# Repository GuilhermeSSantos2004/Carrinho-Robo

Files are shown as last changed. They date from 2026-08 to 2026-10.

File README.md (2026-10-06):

# Carrinho-robô com ESP32 — CUBI-04

> **Project-based Maker Lab — FIAP**  
> **Grupo: Start-up One**

## Integrantes

| Nome | RM |
|---|---|
| Enricco Rossi de Souza Carvalho Miranda | RM551717 |
| Gabriel Marquez Trevisan | RM99227 |
| Guilherme Silva dos Santos | RM551168 |
| Danilo Urze Aldred | RM99465 |
| Laura Claro Mathias | RM98747 |

---

## Resultado final

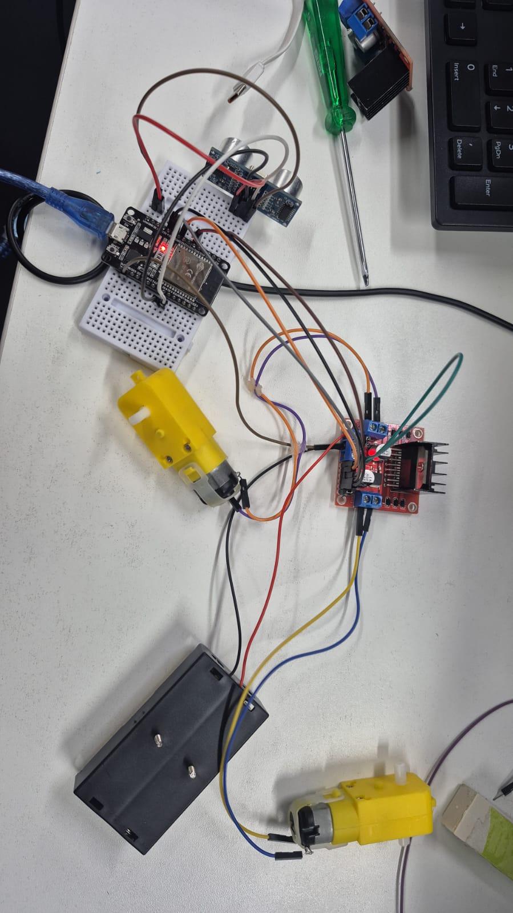
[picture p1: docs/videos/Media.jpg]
Carrinho-robô CUBI-04 montado


O **CUBI-04** é um carrinho-robô funcional desenvolvido para integrar **projeto mecânico, fabricação digital, eletrônica, programação, sensores e comunicação sem fio**. O protótipo utiliza chassi, carenagem e suportes desenvolvidos para impressão 3D, quatro motores TT, ESP32, ponte H L298N e sensores.

### Vídeo de demonstração

- [▶ Assistir ao vídeo final do carrinho](WhatsApp%20Video%202026-09-17%20at%207.53.06%20PM.mp4)
- [▶ Vídeo de evidência em `docs/videos`](docs/videos/MicrosoftTeams-video.mp4)

---

## Funcionalidades implementadas

- 4 motores TT, dois por lado;
- movimentação para frente e para trás;
- curvas para esquerda e direita;
- parada;
- controle remoto pelo celular via Wi-Fi;
- ESP32 operando como Access Point e servidor web;
- controle de velocidade dos motores;
- sensor ultrassônico HC-SR04 para estacionamento de ré;
- bipes progressivos conforme o obstáculo se aproxima;
- bloqueio/interrupção da ré a aproximadamente 5 cm;
- LDR para leitura de luminosidade;
- interface web com modos AUTO, CLARO e ESCURO;
- chassi, carenagem, suportes e travas fabricados em impressão 3D.

---

## Arquitetura do projeto

O celular conecta diretamente à rede criada pelo ESP32. Pela interface web, o usuário envia comandos de movimento. O ESP32 controla a ponte H L298N, que aciona os quatro motores. O HC-SR04 mede a distância durante a ré e o LDR fornece a leitura de luminosidade.

Diagrama elétrico

Documentação elétrica completa: [`hardware/arquitetura/README.md`](hardware/arquitetura/README.md).

---

## Projeto mecânico e fabricação 3D

O desenvolvimento mecânico foi **iterativo**. As peças foram modeladas, impressas, testadas fisicamente e corrigidas de acordo com os problemas encontrados na montagem.

### T01 — chassi/base final

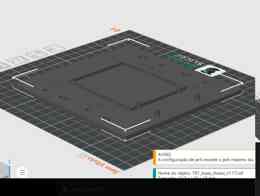
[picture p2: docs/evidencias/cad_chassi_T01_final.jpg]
T01 chassi final


Base estrutural otimizada para aproximadamente **147 × 140 × 10 mm**, com pontos de fixação e espaço para os componentes.

### T02 — carenagem final

T02 carenagem final

A carenagem foi redesenhada para reduzir material e manter acesso aos componentes. As aberturas laterais são funcionais e permitem a passagem/encaixe dos conjuntos dos motores.

### Suportes dos motores

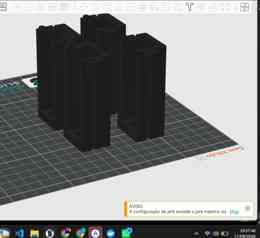
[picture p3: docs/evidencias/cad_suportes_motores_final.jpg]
Suportes finais


Os suportes passaram por várias versões até o conjunto final T03A/T03B v7.

| Peça | Função |
|---|---|
| T01 | Base/chassi estrutural |
| T02 | Carenagem com aberturas funcionais |
| T03A | Suporte do motor v7 |
| T03B | Presilha de retenção v7 |
| T04 | Tampa opcional de 2 mm |
| T05 | Trava vertical suporte ↔ chassi |
| T06 | Pino/parafuso impresso; dois por motor |

Arquivos STL/STEP, fontes e versões: [`cad/`](cad/).  
Pacote final: [`cad/PACOTE_FINAL_VERIFICADO.md`](cad/PACOTE_FINAL_VERIFICADO.md).

---

## Evolução e problemas encontrados

O repositório preserva versões anteriores para demonstrar o **processo de engenharia**, não apenas o resultado final.

Durante os testes foram encontrados problemas reais de fabricação e montagem, entre eles:

- folga lateral nos primeiros suportes de motor;
- laterais frágeis em versões anteriores;
- desalinhamento entre motor, eixo, roda e chassi;
- necessidade de adequação à largura real de aproximadamente 22 mm do motor TT;
- necessidade de reforçar frente e laterais dos suportes;
- ajustes nos furos, parafusos, porcas e travas inferiores;
- colisões e cortes CAD fora do material útil;
- corpos desconectados em versões intermediárias;
- ajustes no encaixe do HC-SR04;
- excesso de suporte detectado durante o fatiamento;
- revisão das aberturas laterais da carenagem para permitir a montagem dos motores.

As correções incluíram centralização do eixo, redução das folgas, reforço estrutural, reposicionamento dos suportes e revisão da carenagem. O histórico detalhado está em [`historico/HISTORICO_PROJETO_CUBI04.md`](historico/HISTORICO_PROJETO_CUBI04.md).

### Registro visual do processo

| Etapa 1 | Etapa 2 |
|---|---|
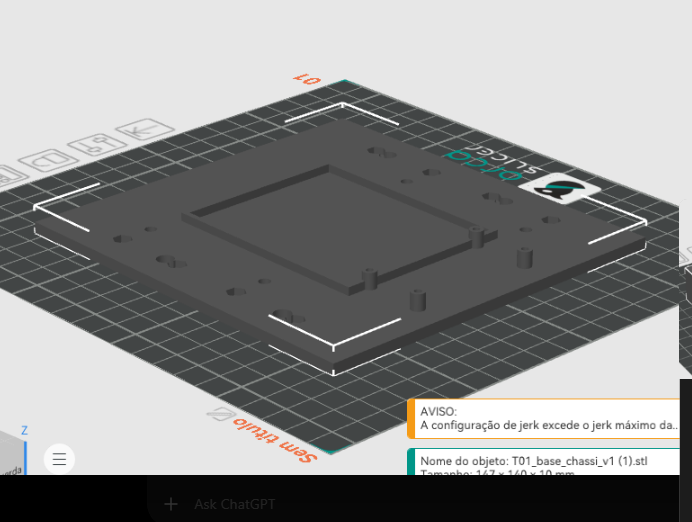
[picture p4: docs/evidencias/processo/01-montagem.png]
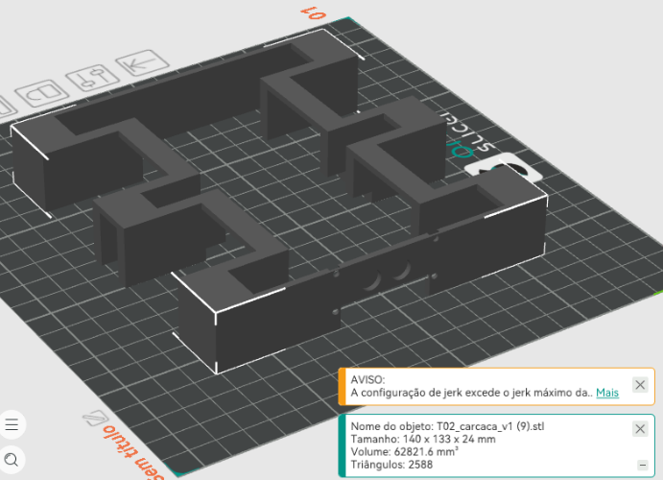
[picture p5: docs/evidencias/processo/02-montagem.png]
|  |  |
| **Etapa 3** | **Etapa 4** |
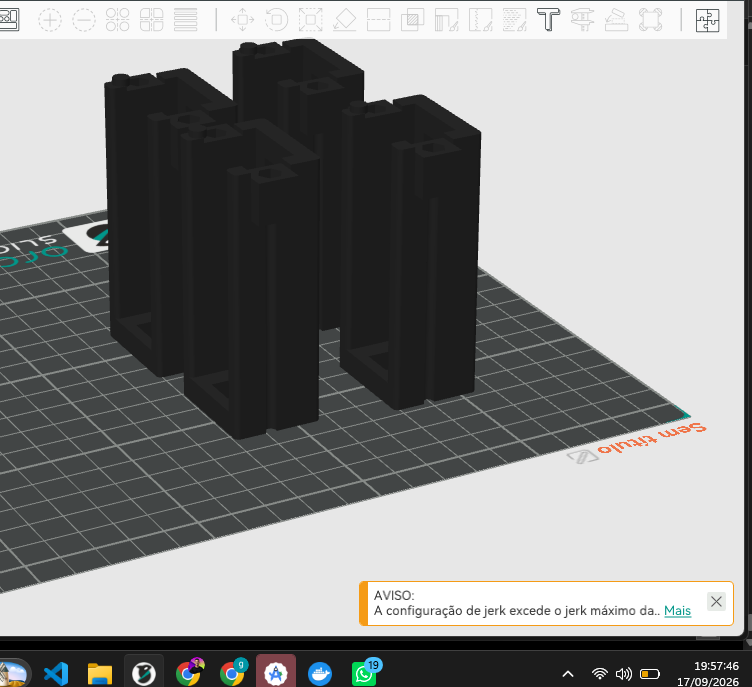
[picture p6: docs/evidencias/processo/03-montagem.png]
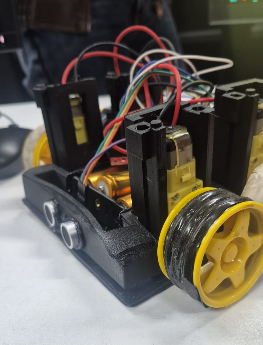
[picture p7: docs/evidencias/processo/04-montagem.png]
|  |  |

Essas imagens foram retiradas da raiz do repositório e centralizadas em `docs/evidencias/processo/`, mantendo a raiz limpa e as evidências fáceis de localizar.

---

## Hardware

| Componente | Especificação / uso |
|---|---|
| ESP32 | DevKit V1 / NodeMCU-ESP32 |
| Ponte H | L298N, dois canais |
| Motores | 4 × TT amarelos, 3–6 V, redução 48:1 |
| Alimentação | suporte com 3 × 18650 em série |
| Ultrassônico | HC-SR04 |
| Luminosidade | LDR |
| Estrutura | peças próprias impressas em 3D |

Lista detalhada: [`hardware/componentes/README.md`](hardware/componentes/README.md).

### ESP32 ↔ L298N

| L298N | ESP32 | Função |
|---|---:|---|
| ENA | GPIO 25 | controle canal A |
| IN1 | GPIO 26 | direção A |
| IN2 | GPIO 27 | direção A |
| ENB | GPIO 33 | controle canal B |
| IN3 | GPIO 32 | direção B |
| IN4 | GPIO 23 | direção B |
| GND | GND | referência comum |

### HC-SR04

| HC-SR04 | ESP32 |
|---|---:|
| VCC | 5 V |
| GND | GND comum |
| TRIG | GPIO 18 |
| ECHO | GPIO 19 via divisor resistivo |

> **Atenção:** o ECHO do HC-SR04 trabalha em nível de 5 V e deve chegar ao ESP32 através do divisor resistivo previsto no projeto.

### Alimentação

O suporte utiliza três células 18650 em série, resultando em aproximadamente **11,1 V nominais e até 12,6 V com as células totalmente carregadas**. O pack alimenta a entrada de potência da L298N. Durante testes, o ESP32 pode ser alimentado separadamente por USB/power bank, sempre mantendo **GND comum**.

Os motores TT são especificados para 3–6 V; portanto, a diferença entre a tensão do pack e a tensão adequada aos motores é uma limitação conhecida do protótipo e deve ser considerada na alimentação/controle.

---

## Software e controle remoto

Firmware principal: [`src/codigo.ino`](src/codigo.ino).  
Versão funcional preservada: [`src/v0.3/carrinho_robo_v0_3.ino`](src/v0.3/carrinho_robo_v0_3.ino).  
Documentação: [`src/README.md`](src/README.md).

O firmware integra Wi-Fi Access Point, servidor HTTP, comandos direcionais, acionamento dos motores, HC-SR04, bloqueio de ré, alertas sonoros no navegador, LDR, interface responsiva para celular e logs de diagnóstico.

### Como executar

1. Confira toda a fiação com o circuito desligado.
2. Alimente o ESP32 por USB/power bank durante os primeiros testes.
3. Abra [`src/codigo.ino`](src/codigo.ino) na Arduino IDE.
4. Selecione a placa compatível com o ESP32 utilizado.
5. Faça o upload do firmware.
6. Abra o Serial Monitor em `115200 baud`.
7. Conecte o celular à rede Wi-Fi criada pelo ESP32.
8. Abra no navegador o endereço exibido/configurado pelo firmware.
9. Teste primeiro parada e movimentos em condição segura, com as rodas livres.
10. Teste o HC-SR04 durante a ré aproximando um obstáculo gradualmente.
11. Varie a iluminação sobre o LDR e confira a leitura/interface.

---

## Experimentos em fase de teste

- [Aula 19 — práticas iniciais com TinyML](experimentos/tinyml-aula19/README.md): leitura bruta do HC-SR04, pré-processamento, classes perto/longe e roteiro para coletar o CSV. **Medições físicas e dataset real pendentes.** Códigos isolados do firmware principal.
- [Tarefa 21 — Inferência TinyML no ESP32](docs/TAREFA21_TINYML.md): inferência com os três HC-SR04 frontais, quatro classes (livre/esquerda/centro/direita), `src/tinyml_inferencia.ino`, `model/model.h` e `docs/dataset.csv`. O dataset desta etapa é **sintético e identificado como tal**; a validação física deve ser demonstrada no vídeo da atividade.

---

## Planejamento e documentação

A organização do projeto também registra requisitos, prioridades e evolução:

- [`organizacao/BACKLOG.md`](organizacao/BACKLOG.md) — backlog;
- [`organizacao/MVP.md`](organizacao/MVP.md) — definição do MVP;
- [`organizacao/MOSCOW.md`](organizacao/MOSCOW.md) — priorização MoSCoW;
- [`organizacao/KANBAN.md`](organizacao/KANBAN.md) — acompanhamento das atividades;
- [`organizacao/DEPENDENCIAS.md`](organizacao/DEPENDENCIAS.md) — dependências;
- [`CHECKPOINT_01_VALIDACAO.md`](CHECKPOINT_01_VALIDACAO.md) — validação da entrega;
- [`docs/EVIDENCIAS_CHECKPOINT.md`](docs/EVIDENCIAS_CHECKPOINT.md) — central de evidências.

---

## Evidências finais

### Carrinho montado

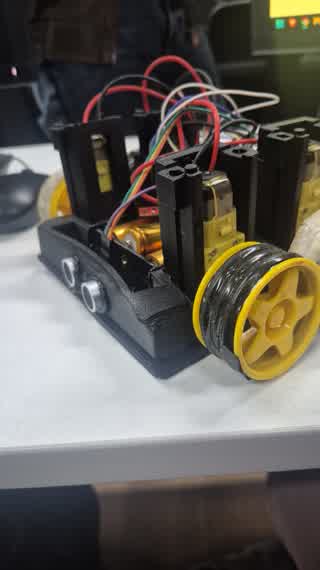
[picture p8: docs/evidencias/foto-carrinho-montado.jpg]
Carrinho final


### Evidências de fabricação

| Chassi T01 | Carenagem T02 | Suportes |
|---|---|---|
|  |  |  |

### Vídeos

- [Vídeo final — 17/09/2026](WhatsApp%20Video%202026-09-17%20at%207.53.06%20PM.mp4)
- [Vídeo de demonstração — Microsoft Teams](docs/videos/MicrosoftTeams-video.mp4)

---

## Organização do repositório

```text
Carrinho-Robo/
├── README.md
├── CHECKPOINT_01_VALIDACAO.md
├── cad/                    # CAD, STL, STEP, fontes e versões
├── docs/
│   ├── dataset.csv         # dataset TinyML da Tarefa 21
│   ├── TAREFA21_TINYML.md  # treinamento, classes e roteiro de teste
│   ├── evidencias/         # fotos, CAD final e processo de montagem
│   │   └── processo/
│   └── videos/             # registros em vídeo
├── model/
│   └── model.h             # pesos do modelo TinyML
├── hardware/
│   ├── arquitetura/        # diagrama e ligações
│   └── componentes/        # componentes utilizados
├── experimentos/           # atividades e protótipos em fase de teste
│   └── tinyml-aula19/       # engenharia do dado com HC-SR04
├── historico/              # problemas, decisões e evolução
├── organizacao/            # backlog, MVP, MoSCoW, Kanban etc.
└── src/                    # firmware do ESP32 + tinyml_inferencia.ino
```

---

## Relação com o Check Point 01

| Critério | Evidência no repositório |
|---|---|
| Projeto mecânico | chassi próprio, CAD, STL/STEP, versões e renders |
| Fabricação digital | peças impressas, imagens do fatiador e registros de montagem |
| Movimentação | quatro motores TT + L298N + comandos direcionais |
| Controle sem fio | ESP32 + Wi-Fi + interface web pelo celular |
| Sensor integrado | HC-SR04 com alerta/bloqueio de ré e LDR |
| Eletrônica | componentes, pinagem, alimentação e diagrama |
| Programação | firmware completo em `src/` |
| Planejamento | backlog, MVP, MoSCoW, Kanban e dependências |
| Evolução | versões anteriores e histórico dos problemas/correções |
| Evidência final | fotos do protótipo e vídeos de demonstração |
| Documentação | README principal + validação + central de evidências |

Para uma conferência objetiva da entrega, consulte também [`CHECKPOINT_01_VALIDACAO.md`](CHECKPOINT_01_VALIDACAO.md).

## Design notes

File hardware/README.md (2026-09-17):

# Hardware

Documentação elétrica e lista dos componentes realmente usados no protótipo atual.

## Conteúdo

- [`arquitetura/`](arquitetura/README.md): alimentação 3S, GND comum, PWM, pinagem do ESP32, L298N, HC-SR04 e LDR;
- [`componentes/`](componentes/README.md): quatro motores TT, três células 18650, resistores, sensores e peças mecânicas atuais.

A proposta antiga de alimentação com pilhas AA/pack 2S permanece apenas no histórico. Para montagem atual, usar a documentação desta pasta e o firmware `src/codigo.ino`.

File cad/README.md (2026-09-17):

# CAD

Esta pasta reúne os modelos mecânicos do carrinho-robô e o histórico das revisões usadas no protótipo atual.

## Estrutura

- [`STL/`](STL/README.md): peças exportadas para impressão 3D e manifesto dos arquivos atuais;
- [`fonte-modelo/`](fonte-modelo/README.md): fontes/arquivos editáveis do processo de modelagem;
- [`versoes/`](versoes/): revisões preservadas para rastreabilidade.

## Estado mecânico atual

O projeto deixou de usar o conceito inicial de chassi 2WD simples e evoluiu para uma estrutura própria com quatro motores TT.

### T01 — base/chassi

- dimensão verificada no STL atual: **147 × 140 × 10 mm**;
- peça única e fechada;
- pedestais altos removidos para reduzir material/tempo;
- furos de montagem integrados ao piso;
- borda externa reduzida em relação às primeiras versões.

### T02 — carcaça

- dimensão verificada no STL atual: **140 × 133 × 24 mm**;
- conceito baixo, deixando os suportes dos motores aparentes/atravessando a região superior;
- aberturas laterais necessárias para a montagem dos suportes;
- região frontal preparada para integração do sensor ultrassônico;
- geometria otimizada para permanecer conectada sem gerar a grande quantidade de suporte observada nas revisões intermediárias.

## Peças relacionadas

| Código | Peça | Estado |
|---|---|---|
| T01 | Base/chassi | versão atual otimizada |
| T02 | Carcaça | versão atual baixa/aberta |
| T03A | Suporte do motor | v7 |
| T03B | Presilha do motor | v7 |
| T04 | Tampa | 2 mm; não obrigatória no conceito atual |
| T05 | Trava | pino vertical com nervuras |
| T06 | Pino/parafuso impresso | 8 previstos, 2 por motor |

O processo detalhado de erros, colisões, fragmentação da carcaça, overhangs e correções está em [`../historico/HISTORICO_PROJETO_CUBI04.md`](../historico/HISTORICO_PROJETO_CUBI04.md).

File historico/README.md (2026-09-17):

# Histórico preservado

A pasta [`2026-08-proposta-2wd`](2026-08-proposta-2wd/README.md) preserva a proposta inicial do projeto: dois motores, chassi simples, rodízio, alimentação AA/2S e firmware anterior.

O desenvolvimento atual evoluiu para quatro motores TT, peças mecânicas próprias impressas em 3D, PWM, sensor ultrassônico de ré, LDR e painel Wi-Fi adaptativo.

## Histórico atual consolidado

O processo completo das revisões mecânicas, erros encontrados, correções, mudanças eletrônicas e evolução do firmware está em:

- [`HISTORICO_PROJETO_CUBI04.md`](HISTORICO_PROJETO_CUBI04.md)

Esse arquivo registra, entre outros pontos:

- evolução do suporte T03A/T03B até v7;
- criação e otimização do T01/T02;
- problemas de overhang e corpos desconectados;
- alterações do encaixe do ultrassônico;
- redução de material da carcaça;
- mudança para quatro motores;
- adoção de PWM;
- mudança para três células 18650 em série;
- LDR no GPIO 34;
- mudança do HC-SR04 para sensor de estacionamento de ré;
- alerta sonoro progressivo;
- bloqueio da ré a 5 cm;
- dificuldades e lições aprendidas.

As pastas históricas continuam preservadas para mostrar a evolução do projeto e não devem ser usadas como especificação do estado físico atual.

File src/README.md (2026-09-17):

# Código-fonte do ESP32

Esta pasta contém o firmware do carrinho-robô. O arquivo [`codigo.ino`](codigo.ino) representa sempre a versão mais recente em uso.

## Versões

| Versão | Arquivo | Alterações principais |
|---:|---|---|
| **v0.2** | [`v0.2/carrinho_robo_v0_2/carrinho_robo_v0_2.ino`](v0.2/carrinho_robo_v0_2/carrinho_robo_v0_2.ino) | HC-SR04, distância no painel e bloqueio frontal experimental |
| **v0.3** | [`v0.3/carrinho_robo_v0_3.ino`](v0.3/carrinho_robo_v0_3.ino) | PWM no L298N, LDR, tema automático claro/escuro, alerta sonoro de ré e bloqueio da ré somente abaixo de 5 cm |

## Estado atual — v0.3

- ESP32 cria a rede Wi-Fi local `tony`;
- senha: `stark369`;
- painel em `http://192.168.4.1`;
- comandos: frente, ré, esquerda, direita e parar;
- velocidade controlada por PWM;
- interface responsiva para celular;
- HC-SR04 mostra a distância em tempo real;
- o ultrassônico funciona como sensor de estacionamento para a ré;
- o alerta sonoro no celular acelera conforme o obstáculo se aproxima;
- abaixo de **5 cm**, a ré é bloqueada;
- a frente continua liberada;
- LDR no GPIO 34 mede a luminosidade;
- tema do painel pode ficar em `AUTO`, `CLARO` ou `ESCURO`;
- no modo `AUTO`, a luminosidade altera o tema do controle;
- o painel mostra percentual de luminosidade e ADC bruto;
- o Serial Monitor registra o LDR aproximadamente a cada 5 segundos.

## Pinagem atual

### L298N

| L298N | ESP32 | Função |
|---|---:|---|
| ENA | GPIO 25 | PWM do lado A |
| IN1 | GPIO 26 | Sentido A |
| IN2 | GPIO 27 | Sentido A |
| ENB | GPIO 33 | PWM do lado B |
| IN3 | GPIO 32 | Sentido B |
| IN4 | GPIO 23 | Sentido B |

Os jumpers `ENA` e `ENB` devem ser removidos quando o PWM é comandado pelo ESP32.

### HC-SR04

| HC-SR04 | ESP32 |
|---|---:|
| VCC | 5 V |
| GND | GND comum |
| TRIG | GPIO 18 |
| ECHO | GPIO 19 através de divisor resistivo |

Divisor utilizado no protótipo com três resistores de 1 kΩ:

```text
ECHO ── 1 kΩ ──┬── GPIO 19
                │
               1 kΩ
                │
               1 kΩ
                │
               GND
```

### LDR

Ligação esperada pelo firmware:

```text
3V3 ── LDR ──┬── GPIO 34
              │
           resistor
              │
             GND
```

O LDR deve trabalhar a partir de **3,3 V**, não de 5 V no GPIO 34.

## Comportamento do sensor de ré

A distância é lida continuamente. O som do navegador funciona como auxílio de estacionamento:

| Distância | Comportamento |
|---:|---|
| acima de 100 cm | sem som |
| 60–100 cm | bipes lentos |
| 40–60 cm | bipes moderados |
| 25–40 cm | bipes rápidos |
| 15–25 cm | bipes mais rápidos |
| 5–15 cm | bipes muito rápidos |
| até 5 cm | som contínuo e ré bloqueada |

O navegador do celular exige uma interação do usuário para liberar áudio; por isso existe o botão **Ativar alerta sonoro**.

## Gravação

1. Abrir [`codigo.ino`](codigo.ino) na Arduino IDE.
2. Instalar/usar `esp32 by Espressif Systems`.
3. Selecionar `ESP32 Dev Module`/`DOIT ESP32 DEVKIT V1` conforme a placa reconhecida.
4. Selecionar a porta do CP210x.
5. Fazer upload.
6. Abrir o Serial Monitor em **115200 baud**.
7. Conectar o celular à rede `tony`.
8. Abrir `http://192.168.4.1`.

Para os primeiros testes, deixar as rodas suspensas e começar com PWM baixo.

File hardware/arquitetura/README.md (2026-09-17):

# Arquitetura eletrônica — estado atual

O protótipo atual usa **ESP32 DevKit V1**, ponte H **L298N**, **4 motores TT amarelos 3–6 V**, sensor ultrassônico **HC-SR04**, LDR e alimentação por células 18650. O ESP32 cria sua própria rede Wi-Fi e hospeda o painel de controle local.

## Alimentação atual

O suporte disponível usa **3 células 18650 em série**:

- tensão nominal aproximada: **11,1 V**;
- tensão máxima com as três células totalmente carregadas: **12,6 V**;
- positivo do pack vai para `12V/Vs` da L298N;
- negativo do pack vai para o GND da L298N;
- durante os testes, o ESP32 pode ser alimentado por USB do notebook ou power bank;
- ESP32, L298N, HC-SR04 e LDR precisam compartilhar referência de GND.

> **Atenção:** os motores TT usados são especificados para 3–6 V. O pack 3S é maior que a tensão nominal dos motores. O firmware limita o PWM para testes, mas PWM não substitui uma alimentação adequada dos motores. Evitar PWM alto e observar aquecimento. Para solução definitiva, usar alimentação/regulação compatível com os motores.

> Nunca ligar 11,1–12,6 V diretamente no `3V3`, `5V` ou GPIO do ESP32.

## ESP32 → L298N

Os jumpers `ENA` e `ENB` foram removidos porque agora há controle de velocidade por PWM.

| ESP32 | L298N | Função |
|---:|---|---|
| GPIO 25 | ENA | PWM do canal A |
| GPIO 26 | IN1 | Direção canal A |
| GPIO 27 | IN2 | Direção canal A |
| GPIO 33 | ENB | PWM do canal B |
| GPIO 32 | IN3 | Direção canal B |
| GPIO 23 | IN4 | Direção canal B |
| GND | GND | Referência comum |

A saída `5V` da L298N não é usada para alimentar o ESP32 no arranjo atual de testes.

## Quatro motores TT → L298N

O carrinho usa dois motores por lado:

| Lado | Ligação |
|---|---|
| 2 motores do lado A | em paralelo em `OUT1/OUT2` |
| 2 motores do lado B | em paralelo em `OUT3/OUT4` |

Os quatro motores são TT amarelos, 3–6 V, redução anunciada de 48:1.

## HC-SR04 → ESP32

| HC-SR04 | Ligação |
|---|---|
| VCC | 5 V do ESP32 enquanto ele é alimentado por USB/power bank |
| GND | GND comum |
| TRIG | GPIO 18 |
| ECHO | GPIO 19 através de divisor de tensão |

O `ECHO` do HC-SR04 pode chegar a aproximadamente 5 V e **não deve ser ligado diretamente** ao GPIO 19. O divisor montado com os resistores disponíveis usa três resistores de 1 kΩ:

```text
ECHO ── 1 kΩ ──┬── GPIO 19
                │
               1 kΩ
                │
               1 kΩ
                │
               GND
```

Isso forma 1 kΩ no ramo superior e 2 kΩ no ramo inferior.

## LDR → ESP32

O sensor de luminosidade usa o **GPIO 34** como entrada analógica.

```text
3V3
 │
 LDR
 │
 ├──────── GPIO 34
 │
 resistor
 │
 GND
```

- alimentar o divisor do LDR com `3V3`;
- não aplicar 5 V ao GPIO 34;
- o firmware faz média de 10 leituras;
- o valor bruto ADC e a luminosidade percentual aparecem no painel;
- logs do LDR são enviados ao Serial Monitor aproximadamente a cada 5 s.

## GND comum

A referência final deve ser comum:

```text
GND ESP32 ─────┬──── GND HC-SR04
               ├──── GND do divisor do ECHO
               ├──── GND do LDR
               └──── GND L298N / negativo da bateria
```

## Comportamento do ultrassônico no firmware atual

O HC-SR04 deixou de bloquear o avanço a 20 cm. Ele agora funciona como **sensor de estacionamento de ré**:

- frente: liberada normalmente;
- ré: liberada enquanto a distância for maior que 5 cm;
- ré a `<= 5 cm`: motores param e o estado passa para `RE_BLOQUEADA`;
- painel mostra a distância;
- durante a ré, o celular emite bipes que aceleram conforme o obstáculo se aproxima;
- em distância crítica, o alerta se torna contínuo.

## Verificação antes de ligar

1. Montar tudo com a alimentação desligada.
2. Conferir polaridade das três 18650.
3. Não conectar o pack 3S diretamente ao ESP32.
4. Conferir GND comum.
5. Conferir divisor do `ECHO` antes de ligar o HC-SR04.
6. Conferir que `ENA` e `ENB` estão sem jumper para PWM.
7. Fazer o primeiro teste com as rodas suspensas.
8. Começar com PWM baixo por causa dos motores 3–6 V.
9. Abrir o Serial Monitor em 115200 baud para conferir sensores e estados.

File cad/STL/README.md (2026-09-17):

# Arquivos STL — estado atual

A pasta `cad/STL` é o destino dos modelos finais/prontos para impressão 3D.

## Arquivos atuais recebidos e validados em 17/09/2026

| Peça | Nome canônico | Dimensões verificadas | Malha | SHA-256 |
|---|---|---:|---|---|
| T01 — base/chassi | `T01_base_chassi_v1.stl` | 147 × 140 × 10 mm | watertight, 1 componente | `eb64ccd5b728aa3ce2f8b160ebef9cd1e81fa0a3d14aa14748b384381642305c` |
| T02 — carcaça | `T02_carcaca_v1.stl` | 140 × 133 × 24 mm | watertight, 1 componente | `9b4c74ce3a754fc66779b3ae2e0d0ffea1d1760d4863c7cae51cd6d99ce83dc4` |

### T01

O chassi atual foi otimizado para impressão mais rápida e menor uso de material. A borda foi reduzida, os pedestais foram removidos e os pontos de fixação passaram para o piso da peça.

### T02

A carcaça atual é baixa, com aberturas necessárias para os suportes dos motores. Ela foi redesenhada após versões que criavam corpos separados ou pontes que exigiam muito suporte de impressão. A região frontal considera a montagem do ultrassônico.

## Demais peças

A montagem também utiliza as revisões atuais do T03A, T03B, T05 e T06. Consulte o histórico consolidado em [`../../historico/HISTORICO_PROJETO_CUBI04.md`](../../historico/HISTORICO_PROJETO_CUBI04.md).

## Regra de versionamento

- manter o código da peça no início do nome (`T01`, `T02`, ...);
- preservar revisões antigas na área de versões/histórico;
- o arquivo sem sufixo adicional deve representar a revisão física vigente;
- registrar no histórico toda alteração que afete encaixe, furação, impressão ou montagem.

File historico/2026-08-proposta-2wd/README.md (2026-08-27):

# Carrinho-robô com ESP32

Documentação inicial da **Tarefa 13 — Requisitos do projeto**, desenvolvida para a disciplina **Project-based Maker Lab**.

## Identificação do projeto

| Campo | Informação |
|---|---|
| Instituição  | FIAP |
| Turma | 4ESPX |
| Professora | Gedeane Kenshima |
| Grupo | Start-up One |
| Data | 13/08/2026 |
| Repositório  | [Acessar o projeto no GitHub](https://github.com/GuilhermeSSantos2004/Carrinho-Robo) |

## Integrantes

| Nome completo | RM |
|---|---|
| Enricco Rossi de Souza Carvalho Miranda | RM551717 |
| Gabriel Marquez Trevisan | RM99227  |
| Guilherme Silva dos Santos | RM551168 |
| Danilo Urze Aldred | RM99465  |
| Laura Claro Mathias | RM98747  |

## 1. Objetivo do projeto

Construir um carrinho-robô pequeno, de baixo custo e fácil montagem, controlado por um celular. O ESP32 criará uma rede Wi-Fi local e uma página simples com os comandos **avançar**, **recuar**, **virar à esquerda**, **virar à direita** e **parar**. Assim, o protótipo não dependerá de internet nem de um aplicativo específico.

## 2. Conceito escolhido

O carrinho utilizará tração diferencial **2WD**: dois motores independentes movimentam as rodas laterais e um rodízio livre apoia a parte dianteira. Para virar, o ESP32 altera o sentido ou a velocidade de cada motor por meio da ponte H L298N. O sensor HC-SR04 fará a detecção frontal de obstáculos.

### Por que essa solução?

- O ESP32 já possui Wi-Fi, evitando um módulo de comunicação adicional.
- Dois motores são suficientes para movimentar e direcionar o carrinho.
- O L298N disponível no grupo controla separadamente o sentido e a velocidade dos dois motores.
- O HC-SR04 acrescenta proteção contra colisões frontais.
- O chassi retangular pode ser cortado em MDF ou acrílico de 3 mm.
- A alimentação separada reduz ruídos dos motores e facilita os primeiros testes.

## 3. Ficha de requisitos

### 3.1 Requisitos físicos e mecânicos

| Item | Requisito definido |
|---|---|
| Dimensões do chassi | 200 mm × 150 mm × 3 mm (comprimento × largura × espessura) |
| Dimensão máxima montada | Aproximadamente 200 mm × 190 mm × 90 mm, incluindo rodas e carenagem |
| Material do chassi | MDF de 3 mm; acrílico de 3 mm é uma alternativa |
| Quantidade de motores | 2 motores DC com caixa de redução, modelo TT, 3–6 V |
| Rodas | 2 rodas de 65 mm para os motores e 1 rodízio livre dianteiro |
| Placa controladora | ESP32 DevKit V1, módulo ESP32-WROOM-32 |
| Driver dos motores | Ponte H L298N de dois canais |
| Sensor de distância | HC-SR04 instalado na parte frontal |
| Fixação | Parafusos M3, espaçadores e abraçadeiras; componentes sem contato direto com o MDF |
| Massa-alvo | Até 1,2 kg com as baterias |
| Carenagem | Cobertura removível de aproximadamente 170 mm × 115 mm × 55 mm |
| Material da carenagem | Placa de polipropileno de 1 mm, acetato grosso ou impressão 3D leve |
| Acesso externo | Conector USB do ESP32 e chave da alimentação dos motores devem ficar acessíveis |
| Ventilação | Aberturas laterais próximas ao ESP32 e ao driver |

### 3.2 Requisitos elétricos e de controle

| Item | Requisito definido |
|---|---|
| Opção A de alimentação | 8 pilhas AA Duracell divididas em dois suportes independentes de 4 pilhas (6 V por suporte) |
| Opção B de alimentação | Pack Li-Ion 7,4 V, 2500 mAh, com BMS |
| Alimentação dos motores | Um suporte de 4 pilhas (6 V) ou a saída principal do pack Li-Ion, conforme a opção escolhida |
| Alimentação do ESP32 e sensor | Saída de 5 V regulada por um conversor LM2596 |
| Referência elétrica | Bateria, LM2596, ESP32, L298N e HC-SR04 devem compartilhar GND |
| Comunicação | Rede Wi-Fi local criada pelo ESP32, sem necessidade de internet |
| Interface | Página web acessada pelo celular, com cinco comandos de movimento |
| Controle de velocidade | PWM independente para cada motor |
| Segurança de software | Parada automática se nenhum comando for recebido por 1 segundo |
| Sensor de obstáculos | HC-SR04 com `TRIG` no GPIO 18 e `ECHO` no GPIO 19 por divisor de tensão |
| Segurança elétrica | Não ligar bateria diretamente ao pino `3V3` ou ao `VIN/5V` sem regulação adequada |

> Na opção com 8 pilhas, **não ligar as oito em série**, pois isso produziria aproximadamente 12 V. Usar dois bancos independentes de 4 pilhas: um para os motores e outro para o LM2596. Não misturar pilhas novas e usadas. O BMS do pack Li-Ion protege as células, mas não substitui o carregador 2S apropriado.

## 4. Lista inicial de materiais e precificação

Preços consultados em **27/08/2026**, sem frete. Os valores podem variar até a compra.

| Quantidade | Componente | Observação | Preço estimado | Referência |
|---:|---|---|---:|---|
| 1 | ESP32 DevKit V1 com cabo USB | Controlador principal; dispensa HC-05/HM-10 | R$ 64,99 | [Casa da Robótica](https://www.casadarobotica.com/placas-embarcadas/esp/placas/placa-esp32-com-wi-fi-bluetooth-esp32s-ide-dual-core-dev-kit-v1-cabo-micro-usb) |
| 1 | Ponte H L298N | Controle dos dois motores | R$ 14,90 | [Eletrogate](https://www.eletrogate.com/ponte-h-dupla-l298n) |
| 1 | Kit chassi 2WD | Inclui base, dois motores, rodas e rodízio | R$ 54,99 | [Casa da Robótica](https://www.casadarobotica.com/robotica/chassi-s/carros/kit-chassi-2-rodas) |
| 1 | Sensor HC-SR04 | Detecção frontal de obstáculos | R$ 9,90 | [Eletrogate](https://www.eletrogate.com/modulo-sensor-de-distancia-ultrassonico-hc-sr04) |
| 1 | Conversor LM2596 | Ajustar a saída para 5,0 V antes de ligar o ESP32 | R$ 8,90 | [Eletrogate](https://www.eletrogate.com/modulo-regulador-de-tensao-step-down-lm2596) |
| 3 kits | Jumpers M-M, M-F e F-F | Um kit de cada tipo | R$ 25,70 | [M-M](https://www.eletrogate.com/jumpers-macho-macho-40-unidades-de-10-cm), [M-F](https://www.eletrogate.com/jumpers-macho-femea-40-unidades-de-20-cm) e [F-F](https://www.eletrogate.com/jumpers-femea-femea-40-unidades-de-10-cm) |
| 2 | Suporte para 4 pilhas AA | Necessários somente na opção com 8 pilhas | R$ 9,80 | [Eletrogate](https://www.eletrogate.com/suporte-para-4-pilhas-aa-branco-) |
| 8 | Pilhas AA Duracell | Opção A de alimentação | R$ 62,00 | [Amazon](https://www.amazon.com.br/Duralock-Pilha-Alcalina-Unidades-Duracell/dp/B07FKWTQPH) |
| 1 | Pack Li-Ion 7,4 V 2500 mAh com BMS | Opção B, substitui as 8 pilhas e os suportes | R$ 66,00 | [RoboCore](https://www.robocore.net/baterias-fontes/pack-bateria-li-ion-7_4v-2500mah-com-bms) |
| 1 | Carregador Li-Ion 2S | Necessário se o grupo não possuir carregador compatível | R$ 37,90 | [RoboCore](https://www.robocore.net/bateria/mini-carregador-bateria-litio-2s) |
| 1 | Mini protoboard 170 pontos | Opcional para os testes | R$ 2,90 | [Eletrogate](https://www.eletrogate.com/mini-protoboard-170-pontos) |
| 2 | Resistores de 1 kΩ e 2 kΩ | Divisor do `ECHO` do HC-SR04 | R$ 1,00 | [Categoria de resistores](https://www.eletrogate.com/resistores) |
| — | Chave, fios, parafusos e carenagem | Verificar materiais disponíveis no grupo/laboratório | A definir | — |

### 4.1 Resumo de custos

| Cenário | Total estimado |
|---|---:|
| Componentes comuns, sem alimentação, frete, mini protoboard e carenagem | R$ 180,38 |
| Total com 8 pilhas Duracell e dois suportes | **R$ 252,18** |
| Total com pack Li-Ion e carregador 2S | **R$ 284,28** |
| Total com pack Li-Ion, caso o grupo já tenha carregador 2S | **R$ 246,38** |

A lista detalhada e a conferência dos itens mínimos estão em [`hardware/componentes/README.md`](hardware/componentes/README.md).

## 5. Posição dos componentes

Adota-se como origem o canto dianteiro esquerdo do chassi. A coordenada **X** é medida da esquerda para a direita e **Y** da frente para trás. As posições são iniciais e podem variar alguns milímetros durante a montagem.

| Componente | Centro aproximado (X, Y) | Justificativa |
|---|---:|---|
| Rodízio livre | (75 mm, 20 mm) | Apoio central na dianteira |
| HC-SR04 | (75 mm, 35 mm) | Campo de detecção livre na dianteira |
| ESP32 | (75 mm, 60 mm) | Protegido, acessível e afastado dos motores |
| L298N | (75 mm, 90 mm) | Próximo do ESP32 e com fios curtos até os motores |
| LM2596 | (75 mm, 115 mm) | Próximo das fontes e da entrada de 5 V do ESP32 |
| Motor esquerdo | (18 mm, 135 mm) | Alinhado ao motor direito |
| Motor direito | (132 mm, 135 mm) | Alinhado ao motor esquerdo |
| Suportes de 4 pilhas AA | (40 mm, 145 mm) e (110 mm, 145 mm) | Distribuem as 8 pilhas em dois bancos independentes |
| Pack Li-Ion alternativo | (75 mm, 145 mm) | Posição central quando esta opção for utilizada |
| Chave dos motores | (15 mm, 175 mm) | Acesso externo sem retirar a carenagem |

## 6. Ligações e pinos do ESP32

### 6.1 ESP32 e L298N

| L298N | ESP32/alimentação | Função |
|---|---:|---|
| ENA | GPIO 25 | PWM do motor esquerdo |
| IN1 | GPIO 26 | Direção do motor esquerdo |
| IN2 | GPIO 27 | Direção do motor esquerdo |
| ENB | GPIO 33 | PWM do motor direito |
| IN3 | GPIO 32 | Direção do motor direito |
| IN4 | GPIO 14 | Direção do motor direito |
| 5 V lógico | Saída de 5 V do LM2596 | Alimentação lógica com o jumper `5V-EN` removido |
| GND | GND comum | Referência elétrica comum |
| 12V/Vs | Banco de motores | Entrada de potência; usar 6 V das AA ou o pack Li-Ion |
| OUT1/OUT2 | Motor esquerdo | Saída do canal A |
| OUT3/OUT4 | Motor direito | Saída do canal B |

Remover os jumpers `ENA` e `ENB` para permitir PWM. Se uma roda girar no sentido oposto ao esperado, inverter os dois fios desse motor ou ajustar a constante de inversão no programa.

### 6.2 ESP32 e HC-SR04

| HC-SR04 | Ligação |
|---|---|
| VCC | Saída regulada de 5 V do LM2596 |
| GND | GND comum |
| TRIG | GPIO 18 |
| ECHO | GPIO 19 por divisor: 1 kΩ em série e 2 kΩ para GND |

O diagrama completo está em [`hardware/arquitetura`](hardware/arquitetura/README.md).

## 7. Requisitos funcionais

| Código | Requisito | Critério de aceitação |
|---|---|---|
| RF-01 | Criar uma rede Wi-Fi própria | A rede aparece no celular até 30 s após ligar o ESP32 |
| RF-02 | Exibir a interface de controle | A página abre no endereço local informado no projeto |
| RF-03 | Executar cinco comandos | O carrinho avança, recua, gira para os dois lados e para |
| RF-04 | Controlar os motores separadamente | Cada motor responde ao canal correspondente do driver |
| RF-05 | Parar em caso de perda de comando | Os dois motores param após 1 s sem atualização |
| RF-06 | Evitar colisão frontal | O avanço é interrompido ao detectar obstáculo a menos de 20 cm |
| RF-07 | Permitir manutenção | A carenagem pode ser retirada sem remover rodas ou motores |

## 8. Requisitos não funcionais

| Código | Requisito |
|---|---|
| RNF-01 | A estrutura deve suportar pequenos impactos de testes em piso plano. |
| RNF-02 | Fios e módulos não podem tocar nas rodas nem ficar soltos. |
| RNF-03 | O centro de massa deve permanecer baixo e entre o rodízio e o eixo das rodas. |
| RNF-04 | A montagem deve usar componentes modulares e facilmente substituíveis. |
| RNF-05 | A carenagem não pode bloquear a antena, o USB, a ventilação ou as rodas. |
| RNF-06 | O protótipo deve funcionar em superfície interna, seca e relativamente lisa. |

## 9. Croqui do chassi

O croqui digital apresenta a vista superior, as dimensões principais, o eixo das rodas e a posição inicial dos componentes.

Croqui digital do chassi

Arquivo em tamanho completo: [`docs/croqui-chassi.svg`](docs/croqui-chassi.svg).

## 10. Registro visual e vídeo de demonstração

Além da documentação técnica e do croqui, o repositório também contém registros visuais do projeto na pasta `docs/videos/`.

### Imagem do projeto

A imagem abaixo pode ser usada como prévia visual do carrinho-robô no GitHub:

Imagem do projeto Carrinho Robô ESP32

Arquivo em tamanho completo: [`docs/videos/Media.jpg`](docs/videos/Media.jpg).

### Vídeo de demonstração

O vídeo de demonstração mostra o projeto **Carrinho Robô ESP32** e pode ser acessado pelo arquivo abaixo:

[Assistir ao vídeo de demonstração](docs/videos/MicrosoftTeams-video.mp4)

> Observação: no GitHub, arquivos `.mp4` podem aparecer como link para visualização ou download, dependendo do navegador e do tamanho do arquivo.

## 11. Sequência sugerida de montagem

1. Cortar e furar o chassi conforme o croqui.
2. Fixar os motores e conferir o alinhamento das rodas.
3. Fixar o rodízio dianteiro e verificar se o chassi fica nivelado.
4. Instalar ESP32, L298N, LM2596 e HC-SR04 sobre suportes ou espaçadores.
5. Prender os dois suportes de pilhas ou o pack Li-Ion com abraçadeiras ou fita de fixação removível.
6. Fazer as ligações com todas as fontes desligadas e conferir o terra comum.
7. Testar um motor por vez com as rodas suspensas.
8. Testar os comandos em baixa velocidade e só depois instalar a carenagem.

## 12. Plano de testes inicial

| Teste | Procedimento | Resultado esperado |
|---|---|---|
| Inspeção | Conferir fios, polaridade e fixações com o carrinho desligado | Nenhum curto, fio solto ou contato com rodas |
| Motor esquerdo | Acionar apenas o canal A com as rodas suspensas | Somente a roda esquerda gira |
| Motor direito | Acionar apenas o canal B com as rodas suspensas | Somente a roda direita gira |
| Movimento | Executar os cinco comandos no piso | Resposta correta a cada comando |
| Comunicação | Afastar o celular gradualmente em ambiente interno | Controle estável na área prevista para demonstração |
| Fail-safe | Interromper o envio de comandos durante o movimento | Parada automática em até 1 s |
| Ultrassônico | Aproximar um obstáculo frontal até menos de 20 cm | Avanço bloqueado e motores parados |
| Carenagem | Instalar a cobertura e repetir um trajeto curto | Sem aquecimento excessivo ou contato com partes móveis |

## 13. Próximas etapas

- Validar as medidas com os componentes físicos disponíveis no laboratório.
- Confirmar preços e comprar a opção de alimentação escolhida.
- Produzir o chassi e a carenagem.
- Validar o firmware e a página de controle em `src/codigo.ino` no carrinho montado.
- Registrar fotos, testes, dificuldades e melhorias neste repositório.

## 14. Estrutura do repositório — Aula 16

A estrutura foi incrementada para separar hardware, modelos CAD, código-fonte, mídia e gestão do projeto:

```text
Carrinho-Robo/
├── README.md
├── hardware/
│   ├── arquitetura/
│   │   ├── README.md
│   │   └── diagrama-ligacoes.svg
│   └── componentes/
│       └── README.md
├── cad/
│   ├── STL/
│   │   └── README.md
│   └── fonte-modelo/
│       └── README.md
├── src/
│   ├── README.md
│   ├── codigo.ino
│   └── v0.2/
│       ├── README.md
│       └── carrinho_robo_v0_2/
│           └── carrinho_robo_v0_2.ino
├── docs/
│   ├── croqui-chassi.svg
│   └── videos/
└── organizacao/
    ├── MVP.md
    ├── MOSCOW.md
    ├── BACKLOG.md
    ├── DEPENDENCIAS.md
    ├── KANBAN.md
    └── planilha-custos-carrinho-robo.xlsx
```

Os arquivos STL devem usar versões no nome, por exemplo `chassi-v0.1.stl` e `chassi-v0.2.stl`. O arquivo editável deve ser guardado em `cad/fonte-modelo/` no formato da ferramenta usada pelo grupo.

## 15. Histórico

| Data | Versão | Alteração observada nos commits | Evidência |
|---|---:|---|---|
| 13/08/2026 | 0.1 | Criação da documentação inicial, ficha de requisitos e croqui (`dee98bf` a `edfc01b`) | [`README.md`](README.md) e [`docs/croqui-chassi.svg`](docs/croqui-chassi.svg) |
| 20/08/2026 | 0.2 | Inclusão da imagem e do vídeo de demonstração (`80e1042`) | [`docs/videos/`](docs/videos/) |
| 26/08/2026 | 0.3 | Inclusão do MVP, MoSCoW, backlog, dependências e Kanban (`b32e213`) | [`organizacao/`](organizacao/) |
| 27/08/2026 | 0.4 | Aula 16: estrutura de hardware/CAD/código; troca para L298N; inclusão do HC-SR04; opções de 8 pilhas AA ou pack Li-Ion; precificação e referências | [`hardware/`](hardware/), [`cad/`](cad/) e [`src/`](src/) |
| 27/08/2026 | 0.5 | Tarefa 18: planilha de custos com fórmulas, lojas e links; firmware identificado e preservado como versão v0.2 com sensor ultrassônico | [`organizacao/planilha-custos-carrinho-robo.xlsx`](organizacao/planilha-custos-carrinho-robo.xlsx) e [`src/v0.2/`](src/v0.2/) |

## 16. Entregáveis da Tarefa 18

| Entregável | Arquivo | Situação |
|---|---|---|
| Planilha de custos do projeto | [`organizacao/planilha-custos-carrinho-robo.xlsx`](organizacao/planilha-custos-carrinho-robo.xlsx) | Concluído |
| Código v0.2 com HC-SR04 | [`src/v0.2/carrinho_robo_v0_2/carrinho_robo_v0_2.ino`](src/v0.2/carrinho_robo_v0_2/carrinho_robo_v0_2.ino) | Concluído |

A planilha permite alterar quantidades e preços unitários; os subtotais e os cenários de alimentação são recalculados automaticamente. O firmware v0.2 mede a distância, mostra o valor no painel web e bloqueia o avanço quando detecta obstáculo a menos de 20 cm.

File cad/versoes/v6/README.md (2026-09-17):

# T03 v6 — suporte aberto recebido

Referência direta da integração v7. STL original preservado, peça única, sem tampa. Fonte CadQuery e STEP desta revisão não acompanharam o STL recebido. Os parâmetros e o relatório foram informados pelo usuário no chat; a tabela abaixo transcreve as dimensões relevantes.

| Parâmetro | mm | Origem |
|---|---:|---|
| Carcaça amarela, Y | 22,0 | medida confirmada pelo usuário |
| Alojamento interno | 22,4 | folga nominal de 0,2 por lado |
| Comprimento, Z | 70 | anúncio |
| Profundidade, X | 18,5 | presumida na v6 |
| Eixo | 5,35 | anúncio |
| Eixo livre | 10 | presumido |
| Centro do eixo sobre fundo da caixa | 9,5 | presumido |
| Base | 7 | projeto |
| Paredes | 5,5 | projeto |
| Altura de paredes sobre a base | 72 | projeto |
| Envelope total STL | 26,5 × 33,4 × 79 | geometria |
| Janela traseira inferior | 16 × 16 | projeto |
| Janela superior | 12 de largura, Z=38…72 | projeto |
| Rasgo inferior | X=5,5…23 | relatório recebido |

O usuário pediu outra extensão de 4 mm no rasgo. Segundo o relatório recebido só restavam 3,5 mm até a parede traseira; a alteração parou em X=5,5 para não cortar essa parede.

**Limitação:** o motor entra por +X e a v6 isolada não tem retenção positiva nessa direção. O atrito lateral não garante que ele fique preso durante o movimento. Fios e conectores não devem segurar o motor.

Na v7 a cavidade foi preservada, foi adicionada uma orelha estrutural para o chassi e a carroceria recebeu batentes. Use quatro `T03_suporte_v6_integrado.stl` da pasta v7 na montagem. O STL desta pasta não tem essa orelha.

O volume informado da v6 é cerca de 30.906 mm³ (~38,3 g se PLA maciço). Essa massa é somente do suporte isolado e não é consumo do fatiador. Não existe furo estrutural novo neste STL original; os furos novos da integração usam 3,46 mm.

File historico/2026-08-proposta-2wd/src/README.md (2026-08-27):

# Código-fonte do ESP32

Esta pasta contém o firmware do carrinho-robô. O arquivo [`codigo.ino`](codigo.ino) sempre representa a versão mais recente.

## Versões

| Versão | Arquivo | Alterações principais |
|---:|---|---|
| **v0.2** | [`v0.2/carrinho_robo_v0_2/carrinho_robo_v0_2.ino`](v0.2/carrinho_robo_v0_2/carrinho_robo_v0_2.ino) | Inclusão do HC-SR04, medição da distância, exibição no painel e bloqueio do avanço abaixo de 20 cm |

O `codigo.ino` e o arquivo versionado da `v0.2` possuem o mesmo conteúdo nesta entrega. A cópia versionada preserva o estado exigido pela **Tarefa 18**.

## Recursos implementados

- rede Wi-Fi própria `Carrinho-ESP32`;
- página web disponível em `http://192.168.4.1`;
- comandos avançar, recuar, esquerda, direita e parar;
- controle de velocidade por PWM na L298N;
- leitura do HC-SR04;
- bloqueio de avanço quando há obstáculo a menos de 20 cm;
- parada automática se o celular deixar de enviar comandos.

## Sensor ultrassônico — versão v0.2

| HC-SR04 | ESP32 | Observação |
|---|---:|---|
| VCC | 5 V regulados | Usar a saída do LM2596 |
| GND | GND | Deve ser comum ao ESP32 e à L298N |
| TRIG | GPIO 18 | Pulso de disparo |
| ECHO | GPIO 19 | Usar divisor de tensão com resistores de 1 kΩ e 2 kΩ |

Comportamento implementado:

1. o sensor é consultado a cada 100 ms;
2. a distância aparece na página web;
3. se um obstáculo estiver a menos de 20 cm, o avanço é interrompido;
4. recuar e girar continuam disponíveis para permitir que o carrinho saia do obstáculo.

## Gravação

1. Abrir `codigo.ino` ou `v0.2/carrinho_robo_v0_2/carrinho_robo_v0_2.ino` na Arduino IDE com o pacote **ESP32 by Espressif Systems 3.x**.
2. Selecionar `ESP32 Dev Module` e a porta COM da placa.
3. Enviar o código.
4. Conectar o celular à rede `Carrinho-ESP32`, senha `carrinho123`.
5. Manter a conexão mesmo se o celular informar que a rede está sem internet.
6. Abrir `http://192.168.4.1`.

Fazer o primeiro teste com as rodas suspensas e conferir o esquema em [`hardware/arquitetura`](../hardware/arquitetura/README.md).

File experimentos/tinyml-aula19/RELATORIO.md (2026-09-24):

# Relatório da atividade — Aula 19 / TinyML

**Estado: preparação concluída; prática física e dados reais pendentes.**

Disciplina: Project-based Maker Lab. Professora: Dra. Gedeane G. S. Kenshima. Grupo: Start-up One.

| Integrante | RM |
|---|---|
| Enricco Rossi de Souza Carvalho Miranda | RM551717 |
| Gabriel Marquez Trevisan | RM99227 |
| Guilherme Silva dos Santos | RM551168 |
| Danilo Urze Aldred | RM99465 |
| Laura Claro Mathias | RM98747 |

## 1. Sensor e variável

Sensor escolhido: **ultrassônico HC-SR04**, conforme hardware documentado do CUBI-04. Confirmar identificação na placa física antes da prática.

- Fenômeno: propagação e reflexão de uma onda ultrassônica no obstáculo.
- Sinal bruto: duração de pulso digital ECHO, em microssegundos (`unsigned long`). A saída elétrica é digital; a grandeza estimada é distância, uma variável quantitativa contínua, representada por `float` em centímetros.
- Conversão: `distancia_cm = duracao_us × 0.0343 / 2`, usando velocidade aproximada do som de 343 m/s. Não há compensação de temperatura.
- Faixa nominal do modelo: **2 a 400 cm**, conforme [datasheet](https://cdn.sparkfun.com/datasheets/Sensors/Proximity/HCSR04.pdf). Não equivale ao mínimo/máximo observado em nossa bancada.
- Valores de referência propostos para o ensaio: alvo parado em torno de 30 cm; alvo variável em aproximadamente 5–100 cm. São posições planejadas, ainda não medidas.
- Faixa escolhida para normalização: 0–100 cm; acima de 100 cm, saturação em 1.0. Leituras fora da faixa nominal ou sem eco são descartadas do processamento.

## 2. Caracterização experimental

Preencher com os arquivos reais; não usar os dados sintéticos dos testes.

| Item | Resultado |
|---|---|
| Data, placa exata e versão do pacote ESP32 | PENDENTE |
| Alvo/material, posição e condições do ambiente | PENDENTE |
| Duração e quantidade de registros por coleta | PENDENTE |
| Mínimo observado válido, ensaio variável | PENDENTE |
| Máximo observado válido, ensaio variável | PENDENTE |
| Média, amplitude e desvio padrão com alvo parado | PENDENTE |
| Leituras sem eco e fora da faixa | PENDENTE |
| Estabilidade observada ao longo do tempo | PENDENTE |
| Ruído com alvo parado e possíveis fontes | PENDENTE |
| Comportamento antes/depois do filtro | PENDENTE |

Critério de análise: relatar os números e as condições do ensaio. Desvio padrão com alvo parado descreve dispersão, mas não determina por si só a exatidão do sensor. Não interpretar movimentos voluntários do alvo como ruído. Para comparar visualmente antes/depois, repetir posições e condições; os sketches não fazem uma comparação pareada simultânea.

## 3. Códigos e pré-processamento

- **Antes:** [leitura_bruta.ino](firmware/leitura_bruta/leitura_bruta.ino), com pulso, distância sem filtragem e status. Mantém valores fora de faixa para diagnóstico.
- **Depois:** [leitura_processada.ino](firmware/leitura_processada/leitura_processada.ino), junto de [processamento.h](firmware/leitura_processada/processamento.h).

Foram implementadas três operações da lista da aula: **média móvel**, **limitação de faixa** e **normalização 0–1**. A janela tem 5 leituras válidas consecutivas; falhas reiniciam a janela. O CSV contém a feature resultante, não a distância bruta.

## 4. Problema e classes

Tipo: **classificação binária**, com duas classes. Feature: média móvel da distância, limitada a 100 cm, dividida por 100 e arredondada para 6 casas.

- Classe **0 — perto:** `feature < 0.2`.
- Classe **1 — longe:** `feature >= 0.2`.

A divisão corresponde a aproximadamente 20 cm depois da filtragem e arredondamento. O limiar foi escolhido para tornar o ensaio reproduzível em bancada. Os rótulos são produzidos por regra explícita; não foi treinado um modelo.

## 5. Dataset e evidências

Arquivo final esperado: `dados/dataset.csv`, com exatamente as colunas `feature,label`. **Ainda não coletado.** Contagens por classe e mínimo/máximo da feature: **PENDENTES**.

Evidências esperadas: capturas do Serial Monitor, foto da montagem, registros originais e condições do ensaio. Usar o [roteiro de coleta](README.md) e o [registro](dados/REGISTRO_COLETA.md).

## 6. Conclusão provisória

A estrutura de aquisição, pré-processamento e rotulagem está preparada. Não é possível concluir sobre estabilidade, ruído, qualidade do dataset ou desempenho no ESP32 sem executar os ensaios e anexar medições reais. A entrega da atividade depende dessas etapas físicas.

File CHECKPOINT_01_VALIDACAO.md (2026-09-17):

# Check Point 01 — Validação da entrega

Este arquivo relaciona os critérios oficiais do Check Point 01 com a documentação atualmente disponível no repositório.

## Grupo

| Integrante | RM |
|---|---|
| Enricco Rossi de Souza Carvalho Miranda | RM551717 |
| Gabriel Marquez Trevisan | RM99227 |
| Guilherme Silva dos Santos | RM551168 |
| Danilo Urze Aldred | RM99465 |
| Laura Claro Mathias | RM98747 |

## 1. Carrinho-robô — 60%

| Critério | Peso | Evidência documental |
|---|---:|---|
| Chassi e projeto mecânico | 15% | Chassi próprio, CAD, arquivos-fonte, STEP/STL, renders, versões e histórico em `cad/` e `historico/`. |
| Movimentação e sistema elétrico | 15% | Firmware contém frente, ré, curvas, parada e PWM; arquitetura documenta ESP32, L298N, quatro motores e alimentação. A pontuação prática depende da demonstração do protótipo físico. |
| Controle remoto sem fio | 10% | Wi-Fi próprio criado pelo ESP32 e interface web local em `192.168.4.1`. |
| Sensor integrado | 10% | HC-SR04 integrado como sensor de estacionamento de ré; LDR integrado à interface. |
| Carenagem e acabamento | 10% | T02 e evolução da carenagem documentados em CAD e histórico. A avaliação de acabamento depende da peça física apresentada. |

## 2. Repositório GitHub — 40%

| Critério | Peso | Evidência no repositório |
|---|---:|---|
| README e apresentação | 5% | Nome, integrantes/RM, objetivo, funcionalidades, imagens de desenvolvimento, registro físico existente e organização do conteúdo no `README.md`. |
| Requisitos, planejamento e evolução | 7% | `organizacao/` contém backlog, MVP, MoSCoW, Kanban, dependências e custos; `historico/` registra decisões, erros e alterações. |
| Projeto mecânico e fabricação | 8% | `cad/` preserva fontes, STEP/STL, renders e diversas versões do desenvolvimento do chassi/suportes/carenagem. |
| Hardware e eletrônica | 5% | `hardware/` documenta componentes, ESP32, quatro motores TT, L298N, bateria 3S, sensores, Wi-Fi, pinagem e diagrama. |
| Software | 7% | `src/` contém firmware principal, versão v0.3 e explicação do funcionamento. |
| Testes e resultados | 4% | `historico/HISTORICO_PROJETO_CUBI04.md` registra problemas, testes, correções e decisões; README resume os principais resultados. |
| Evidências finais | 4% | `docs/EVIDENCIAS_CHECKPOINT.md` centraliza renders, registro físico, vídeo existente, software, hardware e instruções. Evidências físicas apresentadas devem corresponder ao protótipo real. |

## Evidências organizadas

A página [`docs/EVIDENCIAS_CHECKPOINT.md`](docs/EVIDENCIAS_CHECKPOINT.md) reúne os materiais já disponíveis e explica o papel de cada evidência. O README também incorpora imagens do processo diretamente na apresentação principal.

## Adaptação mecânica registrada em 15/09/2026

O histórico registra especificamente o problema de alinhamento do conjunto motor/roda e as adaptações realizadas no chassi e nos suportes: reposicionamento, centralização do eixo, redução de folga, reforço, rodas para fora do perímetro do chassi e preservação das aberturas da carenagem necessárias ao encaixe dos suportes.

## Conferência para apresentação física

A documentação foi organizada para cobrir todos os tópicos pedidos na rubrica. A nota dos critérios físicos continua dependendo do que o protótipo realmente demonstrar ao avaliador. Para tornar a apresentação inequívoca, a demonstração deve mostrar o carrinho montado, alimentação, frente/ré/curvas, controle pelo celular, sensor e carenagem. Uma foto ou vídeo só deve ser chamado de "final" quando representar a montagem efetivamente entregue.

## Roteiro curto para demonstração

1. mostrar o carrinho e a carenagem;
2. mostrar a alimentação e eletrônica;
3. conectar o celular à rede `tony` e abrir `192.168.4.1`;
4. demonstrar frente, ré, esquerda, direita e parada;
5. variar o PWM;
6. demonstrar o HC-SR04 durante a ré;
7. demonstrar o LDR alterando a leitura/interface;
8. mostrar rapidamente os componentes internos e finalizar com o carrinho completo.

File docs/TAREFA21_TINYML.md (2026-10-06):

# Tarefa 21 — Inferência TinyML no ESP32

## Objetivo

Implementar inferência TinyML no ESP32 usando os três sensores ultrassônicos frontais do CUBI-04.

O firmware lê:

- HC-SR04 frente esquerda: TRIG GPIO 16 / ECHO GPIO 17;
- HC-SR04 frente centro: TRIG GPIO 18 / ECHO GPIO 19;
- HC-SR04 frente direita: TRIG GPIO 4 / ECHO GPIO 36 (VP).

O sensor traseiro não participa deste modelo. Ele continua disponível para o firmware principal do carrinho.

## Classes

| Label | Classe | Interpretação |
|---:|---|---|
| 0 | LIVRE | os três sensores indicam espaço frontal suficiente |
| 1 | OBSTACULO_ESQUERDA | obstáculo predominante à esquerda |
| 2 | OBSTACULO_CENTRO | obstáculo predominante no centro |
| 3 | OBSTACULO_DIREITA | obstáculo predominante à direita |

## Dataset

Arquivo obrigatório da entrega:

- `docs/dataset.csv`

Colunas:

```text
esquerda_cm,centro_cm,direita_cm,label
```

O dataset contém **240 amostras sintéticas realistas**, balanceadas em **60 exemplos por classe**.

Os valores foram gerados para representar cenários coerentes com o uso dos HC-SR04 no carrinho:

- leituras aproximadamente entre 5 e 120 cm;
- classe LIVRE com sensores predominantemente acima de ~30–35 cm;
- classes de obstáculo com o sensor correspondente tipicamente abaixo de ~27 cm;
- pequenas variações adicionadas para representar ruído de medição.

> **Transparência:** estes dados não foram capturados fisicamente pelo carrinho. Eles são dados sintéticos usados para permitir o treinamento e a demonstração da inferência. O vídeo exigido pela atividade deve mostrar a validação física no ESP32.

## Modelo treinado

Arquivo:

- `model/model.h`

Foi treinado um classificador de **regressão logística multinomial com Softmax**.

Entradas:

```text
x0 = esquerda_cm / 150
x1 = centro_cm / 150
x2 = direita_cm / 150
```

Saídas:

```text
P(LIVRE)
P(OBSTACULO_ESQUERDA)
P(OBSTACULO_CENTRO)
P(OBSTACULO_DIREITA)
```

Divisão utilizada:

- 75% das amostras para treinamento;
- 25% para teste;
- divisão estratificada entre as quatro classes.

Resultado no conjunto sintético de teste:

```text
Acurácia: 100%
Matriz de confusão:

15  0  0  0
 0 15  0  0
 0  0 15  0
 0  0  0 15
```

Esse resultado mostra que o modelo aprendeu a separação do dataset sintético. **Não significa 100% de acurácia no mundo real**; a validação física depende da geometria do carrinho, ruído, material do obstáculo e posicionamento dos sensores.

## Inferência no ESP32

Sketch obrigatório:

- `src/tinyml_inferencia.ino`

O código:

1. lê os três HC-SR04;
2. realiza três medições por sensor e calcula a média;
3. rejeita leitura sem eco;
4. limita a faixa usada pelo modelo;
5. normaliza as três entradas;
6. calcula os logits do modelo;
7. aplica Softmax;
8. exibe classe, confiança e probabilidades no Serial Monitor.

O modelo foi exportado como pesos em `model.h`, portanto a inferência roda diretamente no ESP32 e não precisa de conexão com internet.

## Como testar

1. Mantenha a ponte H/motores desligados durante o primeiro teste.
2. Para compilar no Arduino IDE, crie uma pasta chamada `tinyml_inferencia` e coloque nela:
   - `src/tinyml_inferencia.ino`;
   - uma cópia de `model/model.h`.
3. Abra `tinyml_inferencia.ino` nessa pasta e grave no ESP32.
4. Abra o Serial Monitor em **115200 baud**.
5. Faça quatro situações:
   - sem obstáculo próximo na frente;
   - obstáculo a aproximadamente 10–20 cm do sensor esquerdo;
   - obstáculo a aproximadamente 10–20 cm do sensor central;
   - obstáculo a aproximadamente 10–20 cm do sensor direito.
6. Observe a mudança da classe e da confiança.

Exemplo esperado:

```text
---------- INFERENCIA TINYML ----------
ESQ: 74.1 cm | CENTRO: 13.8 cm | DIR: 80.2 cm
CLASSE: OBSTACULO_CENTRO | CONFIANCA: 99.8%
ACAO SUGERIDA: PARAR / ESCOLHER LADO LIVRE
---------------------------------------
```

## Roteiro do vídeo da entrega

Sugestão de vídeo curto:

1. mostrar fisicamente o carrinho e os três HC-SR04 frontais;
2. mostrar o Serial Monitor;
3. deixar a frente livre e mostrar `LIVRE`;
4. aproximar um objeto do sensor esquerdo e mostrar `OBSTACULO_ESQUERDA`;
5. repetir no centro;
6. repetir na direita;
7. mostrar a confiança mudando em tempo real.

## Estrutura da entrega

```text
Carrinho-Robo/
├── src/
│   └── tinyml_inferencia.ino
├── model/
│   └── model.h
└── docs/
    └── dataset.csv
```

Os arquivos antigos do CUBI-04 foram mantidos. O firmware principal continua em `src/codigo.ino`.

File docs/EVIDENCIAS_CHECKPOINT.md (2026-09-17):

# Evidências — Check Point 01

Este documento organiza as evidências já existentes no repositório e relaciona cada uma ao desenvolvimento do carrinho-robô.

## Equipe

| Integrante | RM |
|---|---|
| Enricco Rossi de Souza Carvalho Miranda | RM551717 |
| Gabriel Marquez Trevisan | RM99227 |
| Guilherme Silva dos Santos | RM551168 |
| Danilo Urze Aldred | RM99465 |
| Laura Claro Mathias | RM98747 |

## 1. Processo de projeto mecânico

O projeto possui registros de múltiplas versões. A permanência dessas versões no GitHub é intencional e demonstra o processo de desenvolvimento, erros encontrados e alterações realizadas.

### Arquitetura inicial

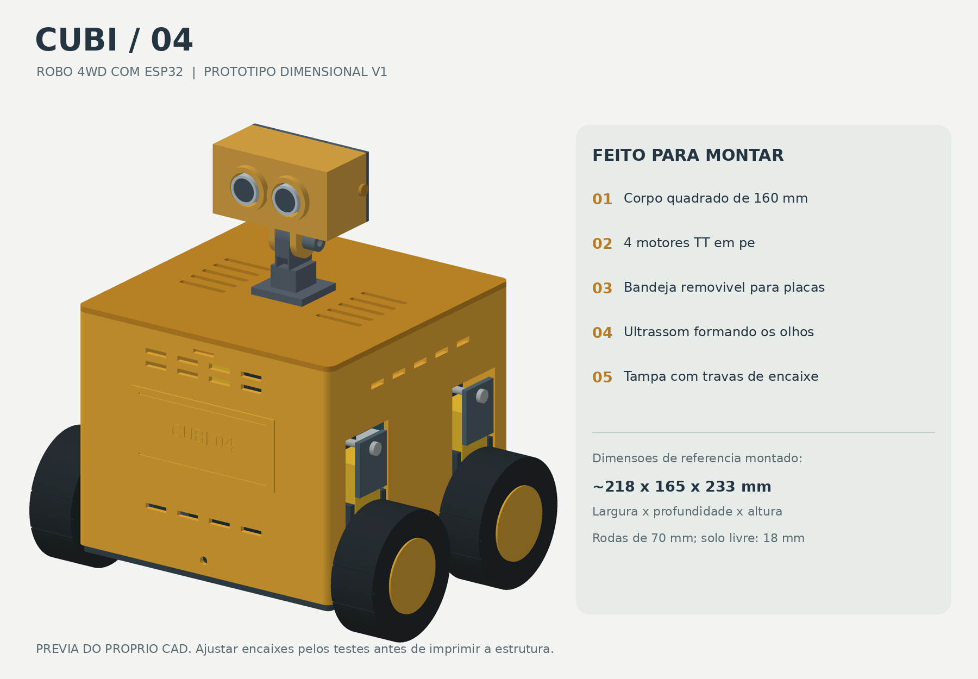
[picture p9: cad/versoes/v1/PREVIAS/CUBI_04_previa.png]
Render inicial


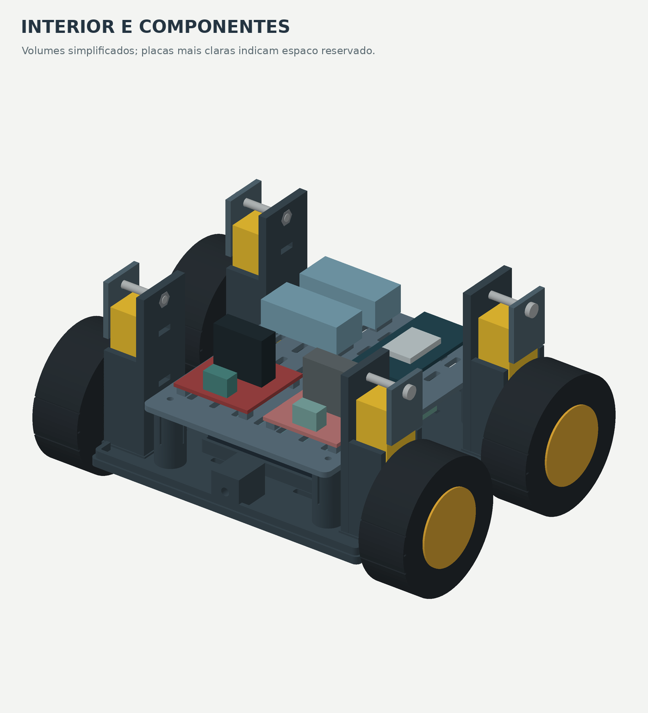
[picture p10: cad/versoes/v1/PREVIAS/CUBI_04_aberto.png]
Vista aberta inicial


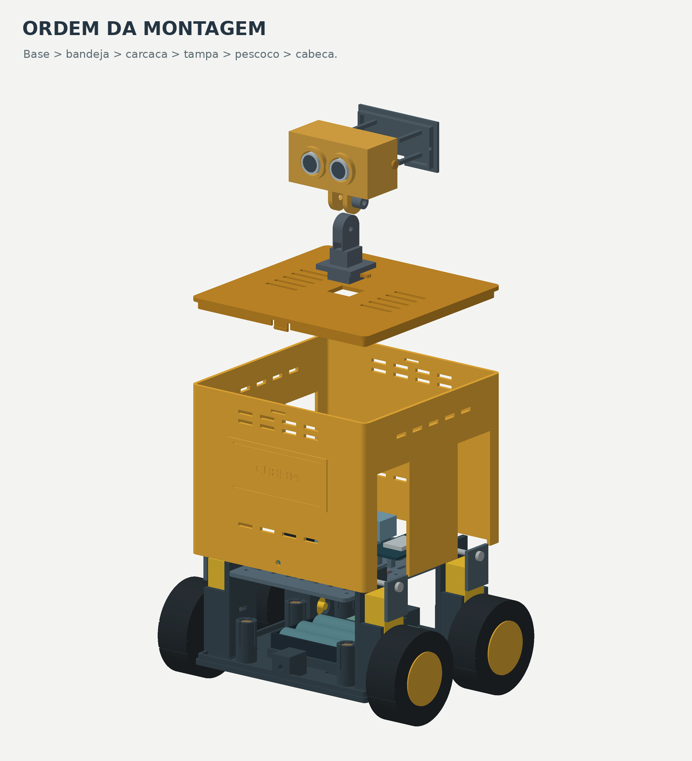
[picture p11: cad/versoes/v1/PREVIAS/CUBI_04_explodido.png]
Vista explodida inicial


Essa etapa representa uma proposta anterior e não deve ser interpretada como a configuração mecânica final. O conceito evoluiu posteriormente para quatro motores TT, L298N, chassi menor e carenagem baixa.

## 2. Evolução dos suportes dos motores

### Versão v2

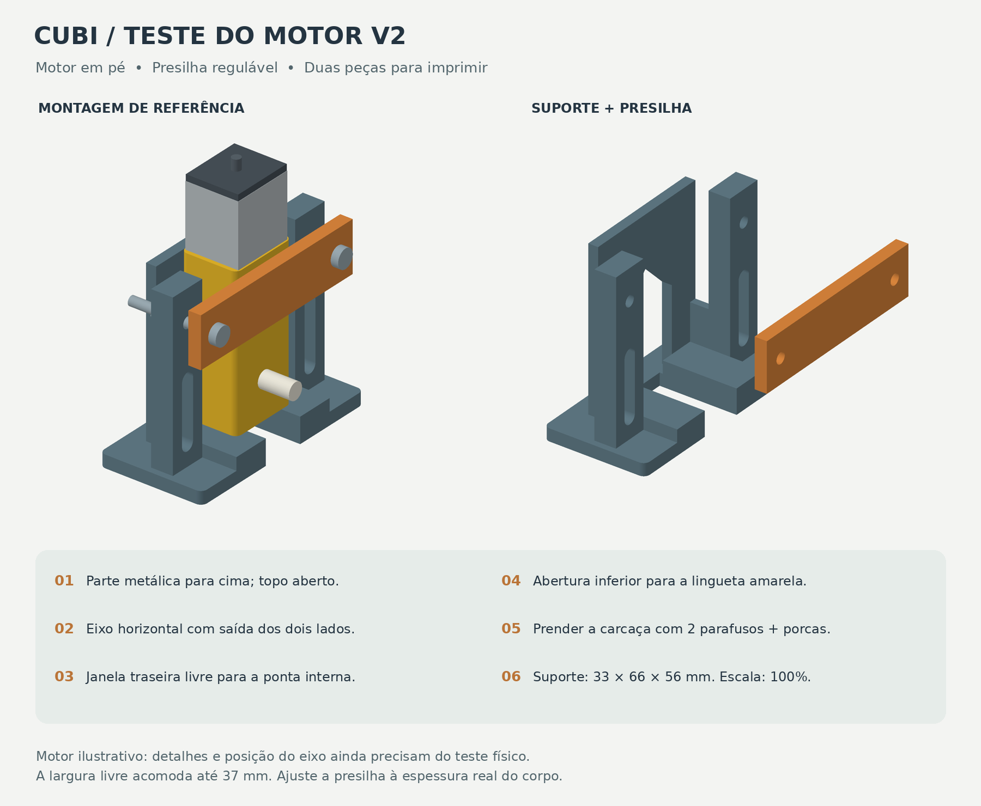
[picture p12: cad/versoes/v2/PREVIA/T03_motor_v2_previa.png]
Suporte de motor v2


### Versão v3

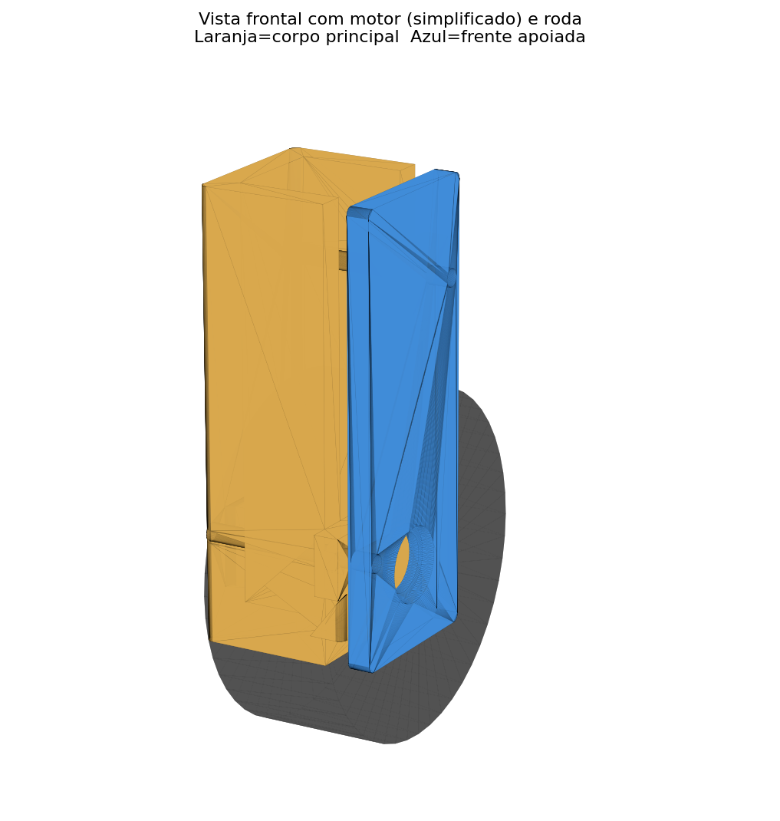
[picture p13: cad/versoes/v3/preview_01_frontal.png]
Suporte de motor v3


O suporte passou por sucessivas revisões até o conceito T03A/T03B v7. Entre os motivos estavam folga lateral, fragilidade frontal, encaixe do motor, posição do eixo e necessidade de alinhar as rodas com o chassi.

## 3. Adaptação do chassi e alinhamento das rodas — 15/09/2026

Durante a montagem foi identificado que o posicionamento inicialmente adotado não garantia que o conjunto motor/eixo/roda permanecesse corretamente alinhado. O problema não era apenas estético: a roda precisava permanecer para fora da estrutura, sem interferir no chassi ou na carenagem.

Foram realizados:

- reposicionamento dos suportes no chassi;
- ajuste da largura interna à dimensão real do motor TT;
- centralização do eixo;
- redução de folgas laterais;
- reforço de regiões frágeis;
- revisão das fixações;
- manutenção das aberturas laterais da carenagem para passagem/encaixe dos suportes;
- uso de travas e pontos de fixação acessíveis para montagem e manutenção.

O histórico completo está em [`../historico/HISTORICO_PROJETO_CUBI04.md`](../historico/HISTORICO_PROJETO_CUBI04.md).

## 4. Chassi e carenagem atuais

A documentação atual identifica:

- T01 — base/chassi otimizado;
- T02 — carenagem baixa com aberturas funcionais;
- T03A — suporte do motor;
- T03B — presilha;
- T04 — tampa opcional;
- T05 — trava vertical;
- T06 — pino/parafuso impresso.

Os modelos e a evolução mecânica estão em [`../cad/`](../cad/).

## 5. Hardware e integração

A configuração documentada utiliza ESP32, L298N, quatro motores TT, pack de três 18650, HC-SR04 e LDR. O diagrama elétrico está disponível abaixo.

Diagrama de ligações

A pinagem e os cuidados de alimentação estão detalhados em [`../hardware/arquitetura/README.md`](../hardware/arquitetura/README.md).

## 6. Sensor integrado

O HC-SR04 é utilizado no firmware atual como sensor de estacionamento de ré. Conforme a distância diminui, o navegador produz alertas progressivamente mais rápidos. A 5 cm ou menos, o comando de ré é interrompido.

O LDR no GPIO 34 também possui função de software: fornece a leitura de luminosidade e, no modo AUTO, participa da seleção do tema da interface.

## 7. Controle remoto sem fio

O ESP32 cria a rede Wi-Fi `tony`. O celular conecta diretamente ao ESP32 e acessa o painel em `192.168.4.1`. O firmware contém comandos de frente, ré, esquerda, direita, parada e controle PWM.

## 8. Registro físico e vídeo existentes

### Registro físico

Registro físico disponível

### Vídeo

[MicrosoftTeams-video.mp4](videos/MicrosoftTeams-video.mp4)

Esses arquivos são preservados como evidências já existentes. O conteúdo do vídeo não é descrito aqui além do que foi efetivamente verificado pelo repositório; na apresentação, a equipe deve demonstrar claramente as funções do protótipo que estiverem operacionais.

## 9. Software

O código atual está em [`../src/codigo.ino`](../src/codigo.ino), com versão v0.3 preservada em [`../src/v0.3/`](../src/v0.3/). A documentação de funcionamento está em [`../src/README.md`](../src/README.md).

## 10. Planejamento e evolução

Os documentos de requisitos e planejamento estão em [`../organizacao/`](../organizacao/), incluindo backlog, MVP, MoSCoW, Kanban, dependências e custos. O histórico registra dificuldades e correções para mostrar o processo, e não somente o resultado final.

## 11. Uso básico

1. conferir a fiação com o circuito desligado;
2. alimentar o ESP32 por USB/power bank;
3. carregar `src/codigo.ino` no ESP32;
4. conectar o celular à rede `tony`;
5. acessar `192.168.4.1`;
6. ativar o áudio do painel;
7. iniciar com PWM baixo;
8. testar os comandos direcionais;
9. testar o HC-SR04 durante a ré;
10. testar o LDR variando a iluminação.

## 12. Observação sobre evidências finais

Renders, arquivos CAD e registros de desenvolvimento comprovam o processo de projeto. Uma fotografia real da montagem final e uma demonstração física completa devem representar o protótipo efetivamente apresentado; não devem ser substituídas por imagem gerada ou por uma versão CAD diferente da montagem real.

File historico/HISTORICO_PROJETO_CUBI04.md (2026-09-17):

# Histórico do projeto CUBI-04 — modificações, erros e correções

Este documento consolida o processo real de desenvolvimento mecânico, eletrônico e de firmware do carrinho-robô. O objetivo é registrar não só o resultado final, mas também as dificuldades, hipóteses erradas, correções e decisões que levaram ao estado atual.

> Os horários exatos das conversas não foram preservados. As sessões abaixo estão organizadas pelas datas e pela ordem real das alterações conhecidas.

---

## Sessão 1 — 15/09/2026

Foco: suporte do motor (T03A), presilha (T03B), encaixe no chassi e alinhamento das rodas.

- **v3**: suporte com largura interna 22,4 mm, reforços estruturais e furos de 3,6 mm.
- **v4**: reforços removidos após teste/avaliação; janela frontal e rasgo de eixo ampliado.
- **v5**: tampa frontal passou para encaixe tipo rabo-de-andorinha e o rasgo da base foi estendido.
- **v6**: tampa frontal eliminada; frente aberta e presilha superior adotada como retenção do motor; furos ajustados para 3,46 mm.
- **v7 — versão adotada**: suporte T03A separado da presilha T03B; dois furos de 4,5 mm para fixação no chassi e buchas com rebaixo para porca.

### Problema de encaixe do chassi e alinhamento das rodas — 15/09/2026

Durante a montagem física foi identificado que a posição inicialmente prevista para os suportes não deixava o conjunto motor/roda corretamente alinhado com a lateral do chassi. Em algumas tentativas, o suporte ficava afastado demais da borda e a roda não ocupava a posição desejada para girar livremente fora da estrutura.

Também foi observado que as aberturas da carcaça precisavam respeitar a região real ocupada pelos suportes. Fechar essas regiões impedia a entrada/encaixe das peças e dificultava a montagem dos motores.

**Adaptações realizadas:**

1. reposicionamento dos suportes dos motores em relação às bordas do T01;
2. centralização do eixo do motor para melhorar o alinhamento da roda;
3. ajuste do suporte para a largura real do motor TT, reduzindo folgas laterais;
4. reforço das laterais e da região frontal do suporte após quebras observadas nas versões anteriores;
5. manutenção das rodas para fora do perímetro útil do chassi, evitando contato com a base/carenagem;
6. revisão das aberturas laterais do T02 para permitir que os suportes atravessem/encaixem corretamente;
7. preservação de acesso aos pontos de fixação para facilitar montagem, desmontagem e manutenção;
8. uso das travas inferiores e parafusos/porcas como parte do sistema de fixação dos suportes.

**Resultado da alteração:** o conceito mecânico passou a considerar o conjunto completo — chassi, suporte, motor, eixo e roda — em vez de posicionar cada peça isoladamente. Essa revisão foi necessária para manter as rodas alinhadas, livres para girar e com os suportes efetivamente encaixáveis na estrutura.

### Dificuldades dessa etapa

1. Folga excessiva em versões iniciais.
2. Região frontal frágil durante o aperto.
3. Necessidade de permitir montagem/desmontagem rápida do motor.
4. Ajuste dos furos a partir dos parafusos realmente disponíveis.
5. Posição inicial do suporte não garantia alinhamento adequado da roda.
6. Aberturas da carcaça precisavam acompanhar o volume real ocupado pelos suportes.

---

## Sessão 2 — 17/09/2026 — mecânica

### Criação do T01, T02 e T04

A primeira arquitetura usava:

- base de 163 × 156 mm;
- piso de 4 mm;
- quatro pedestais para suportes;
- guia de bateria;
- apoio para ESP32;
- carcaça envolvendo os motores;
- tampa superior parafusada.

### Reposicionamento dos motores

A geometria foi alterada para deixar as rodas realmente para fora do chassi e alinhar a face do motor com a borda útil da estrutura. Essa alteração consolidou os testes de encaixe e alinhamento iniciados em 15/09.

### Porcas cativas

**Problema:** os furos de fixação chegavam ao chassi sem espaço físico suficiente para alojar a porca.

**Correção:** criação de rebaixo hexagonal de aproximadamente 6 mm entre-chaves e 2,6 mm de profundidade.

### Overhang e peças saindo da base

**Problema:** pedestal e um dos apoios do ESP32 ultrapassavam o retângulo real da base.

**Correção:** suportes foram recuados para dentro da área útil e os apoios internos foram reposicionados.

### Trava suporte ↔ chassi

Foram testadas abordagens diferentes:

1. furo/pino lateral — descartado porque o corte estava fora do material real;
2. trava vertical de cima para baixo — adotada;
3. ajuste fino das nervuras para garantir contato real com material sólido.

Esse processo mostrou que uma operação booleana aparentemente válida não garante que o corte tenha atingido a peça.

### Carcaça mais baixa

A carcaça foi reduzida para ficar poucos milímetros acima dos suportes. A trava passou a se relacionar diretamente com a carcaça.

Durante essa etapa ocorreram três erros importantes:

- pino projetado em região onde não existia parede real;
- conta de altura sem considerar corretamente a espessura do piso;
- pequena colisão residual por margem geométrica incorreta.

Todos foram corrigidos após conferência da geometria real.

### Ultrassônico na carcaça

O encaixe do HC-SR04 passou por várias revisões:

- tentativa inicial com dois furos assumidos;
- tentativa com rasgo único;
- retorno para dois furos;
- revisão do espaçamento real;
- tentativa de tubos salientes ao redor dos sensores;
- remoção dos tubos a pedido, mantendo acabamento mais raso;
- rebaixos internos para esconder cabeças de fixação.

A principal lição foi não congelar dimensões assumidas antes de validar a peça física.

### Tampa

A tampa foi reduzida de 3 mm para 2 mm para economizar material e tempo de impressão. No conceito mecânico atual ela não é peça obrigatória.

### T06 — pino/parafuso impresso

Foi criado um pino com cabeça e nervuras de atrito para substituir parte da ferragem metálica. O projeto usa dois pontos de fixação por motor, oito no total.

### Otimização do chassi

Para reduzir tempo e material:

- pedestais foram removidos;
- os furos passaram diretamente para o piso;
- dimensões externas foram reduzidas;
- borda/guia periférica foi removida;
- a carcaça precisou receber novas regiões de ligação para continuar sendo uma peça única.

### Redesign da carcaça

A carcaça deixou de envolver completamente os suportes dos motores. O conceito atual é uma carcaça baixa, com os suportes atravessando/ficando visíveis.

Ocorreram tentativas em que a geometria ficou dividida em vários componentes independentes. A correção foi criar material contínuo na parte inferior ligando frente e traseira sem colidir com suportes, bateria e ESP32.

### Suportes de impressão indesejados

O fatiador indicava aproximadamente 45 minutos adicionais de material de suporte em uma região de ponte.

Foram adicionadas e reposicionadas colunas de apoio. Posteriormente foi descoberta a causa raiz: a região bloqueada pelo suporte do motor era bem maior do que a estimada inicialmente.

A correção foi feita medindo a colisão real e criando faixas estruturais somente onde necessário.

### Otimização final da carcaça

A faixa estrutural larga foi reduzida na maior parte da peça e mantida mais larga apenas ao redor dos quatro suportes. O volume caiu aproximadamente de 68.126 mm³ para 62.822 mm³, cerca de 8% de redução, mantendo a peça conectada.

---

## Sessão 2 — 17/09/2026 — eletrônica e firmware

### ESP32 e comunicação USB

A placa ESP32 usa interface USB-UART CP2102. Após instalação do driver Silicon Labs CP210x, a placa passou a ser reconhecida corretamente pelo Windows e os primeiros testes de firmware foram executados.

### Wi-Fi local

O ESP32 passou a criar sua própria rede, sem roteador e sem internet:

- SSID: `tony`;
- senha: `stark369`;
- IP: `192.168.4.1`;
- servidor HTTP local;
- DNS/captive portal para facilitar abertura do painel.

### Quatro motores e L298N

O projeto passou a utilizar quatro motores TT, dois por lado, ligados aos dois canais do L298N.

Pinagem atual:

| Função | GPIO |
|---|---:|
| ENA / PWM | 25 |
| IN1 | 26 |
| IN2 | 27 |
| ENB / PWM | 33 |
| IN3 | 32 |
| IN4 | 23 |

Os jumpers ENA/ENB foram removidos e o controle de velocidade passou a ser feito por PWM.

### Alimentação

A alimentação usada no protótipo mudou para três células 18650 em série:

- 11,1 V nominal;
- até 12,6 V carregadas;
- pack alimenta a entrada de potência da L298N;
- ESP32 permanece alimentado por USB/power bank durante os testes;
- GND compartilhado entre os circuitos.

**Risco identificado:** os motores TT são 3–6 V e a tensão do pack 3S é superior à especificação deles. O PWM baixo foi usado apenas como limitação de teste e não substitui uma fonte adequada para os motores.

### HC-SR04

O sensor utiliza:

- TRIG no GPIO 18;
- ECHO no GPIO 19;
- divisor de tensão construído com três resistores de 1 kΩ: 1 kΩ no ramo superior e 2 kΩ no ramo para GND.

A função do ultrassônico também mudou durante o desenvolvimento.

**Versão anterior:** bloquear avanço a aproximadamente 20 cm.

**Versão atual:** atuar como sensor de estacionamento para a ré.

- frente permanece liberada;
- a ré funciona normalmente acima de 5 cm;
- a 5 cm ou menos, a ré é bloqueada;
- o celular emite bipes cada vez mais rápidos conforme o obstáculo se aproxima;
- na faixa crítica, o alerta se torna contínuo.

### LDR

Foi adicionado um LDR ao GPIO 34 para adaptar a interface à iluminação do ambiente.

O painel possui três modos:

- `AUTO`;
- `CLARO`;
- `ESCURO`.

No modo automático, a luminosidade altera o tema. O firmware também mostra o ADC bruto para permitir calibração do sensor e grava logs no Serial Monitor aproximadamente a cada 5 segundos.

Ligação prevista:

```text
3V3 ── LDR ──┬── GPIO 34
              │
           resistor
              │
             GND
```

### Interface web

A interface atual mostra:

- estado do carrinho;
- distância do ultrassônico;
- PWM atual;
- luminosidade em percentual;
- ADC bruto do LDR;
- indicação de dia/meia-luz/noite;
- seleção de tema automático/claro/escuro;
- botão para ativar áudio no navegador;
- comandos direcionais para toque no celular.

---

## Dificuldades e ajustes mais relevantes

1. **Dimensões assumidas do CAD causaram retrabalho.** Sempre que possível, passaram a ser usadas medições ou testes contra a geometria real.
2. **Malha válida não significa corte válido.** Houve cortes fora da peça que não mudavam o sólido.
3. **Uma malha fechada pode conter vários corpos soltos.** A validação passou a incluir contagem de componentes conectados.
4. **O fatiador revelou problemas que o CAD sozinho não mostrava**, principalmente pontes sem apoio e tempo excessivo de suporte.
5. **A carcaça precisava conciliar motores, bateria, ESP32 e impressão rápida**, o que levou ao conceito baixo e aberto atual.
6. **O ultrassônico mudou de função conforme o uso real do carrinho:** saiu de bloqueio frontal para auxílio de ré.
7. **O LDR precisava ser observável para calibração.** Por isso foram adicionados ADC bruto e logs periódicos.
8. **A alimentação disponível não é ideal para os motores 3–6 V.** Essa limitação permanece documentada para evitar tratar PWM como regulador de tensão.
9. **O alinhamento das rodas exigiu adaptação física do chassi e dos suportes.** A posição do motor passou a ser definida considerando eixo, roda e borda real da estrutura.
10. **As aberturas laterais da carcaça são funcionais.** Elas precisam permanecer abertas para permitir a entrada dos suportes e o correto encaixe do conjunto mecânico.

---

## Estado atual das peças

| Peça | Arquivo | Estado |
|---|---|---|
| T01 | `T01_base_chassi_v1.stl` | chassi/base atual otimizado |
| T02 | `T02_carcaca_v1.stl` | carcaça baixa atual, com aberturas para suportes e sensor |
| T03A | `T03A_suporte_motor_aberto_v7.stl` | suporte v7 |
| T03B | `T03B_presilha_v7.stl` | presilha v7 |
| T04 | `T04_tampa_v1.stl` | tampa 2 mm, não obrigatória no conceito atual |
| T05 | `T05_trava_suporte_v1.stl` | trava vertical |
| T06 | `T06_parafuso_impresso_v1.stl` | pino/parafuso impresso; 8 unidades previstas |

## Estado atual do firmware

A versão funcional atual é documentada como **v0.3** e inclui Wi-Fi local, PWM, quatro motores, HC-SR04 de ré, LDR, temas de interface e logs de diagnóstico.

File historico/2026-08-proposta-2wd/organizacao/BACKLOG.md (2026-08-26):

# Backlog do projeto

## Legenda

- **P0:** indispensável para o MVP;
- **P1:** necessário para o produto final;
- **P2:** melhoria opcional;
- **Estados:** A fazer, Em andamento, Em teste, Bloqueado ou Concluído.

## Backlog priorizado

| ID | Prioridade | Tarefa | Responsável | Dependência | Prazo | Critério de aceitação | Estado em 25/08/2026 |
|---|---|---|---|---|---:|---|---|
| BK-01 | P0 | Consolidar requisitos e croqui | Laura | - | 25/08 | Documentação revisada no GitHub | Concluído |
| BK-02 | P0 | Desenvolver firmware e página Wi-Fi | Guilherme | BK-01 | 25/08 | Código compila e cria a rede local | Concluído |
| BK-03 | P0 | Gravar firmware no ESP32 | Guilherme | BK-02 | 25/08 | Upload finalizado e hash verificado | Concluído |
| BK-04 | P0 | Conferir L298N, motores, bateria e HC-SR04 | Gabriel | BK-01 | 26/08 | Componentes identificados e sem dano visível | Em andamento |
| BK-05 | P0 | Montar alimentação e GND comum | Gabriel | BK-04 | 26/08 | Tensões conferidas antes de ligar os módulos | A fazer |
| BK-06 | P0 | Ligar ESP32 à L298N | Gabriel | BK-05 | 27/08 | GPIOs conectados conforme o firmware | A fazer |
| BK-07 | P0 | Testar cada motor separadamente | Danilo | BK-06 | 27/08 | Cada canal gira apenas o motor correspondente | A fazer |
| BK-08 | P0 | Corrigir sentido dos motores | Guilherme | BK-07 | 27/08 | Comandos produzem o sentido esperado | A fazer |
| BK-09 | P0 | Testar página pelo celular | Guilherme | BK-03, BK-07 | 28/08 | Cinco comandos funcionam pelo Wi-Fi | A fazer |
| BK-10 | P0 | Produzir base provisória do MVP | Enricco | BK-04 | 28/08 | Componentes ficam firmes e rodas giram livres | A fazer |
| BK-11 | P0 | Integrar eletrônica à base provisória | Danilo | BK-05, BK-10 | 29/08 | Carrinho montado sem cabos nas partes móveis | A fazer |
| BK-12 | P0 | Validar MVP integrado | Todos | BK-08, BK-09, BK-11 | 29/08 | Todos os critérios MVP-01 a MVP-08 aprovados | A fazer |
| BK-13 | P0 | Publicar documentação da Tarefa 17 | Laura | BK-12 | 01/09 | Cinco entregáveis disponíveis em `/organizacao` | A fazer |
| BK-14 | P1 | Medir componentes com paquímetro | Enricco | BK-04 | 03/09 | Medidas reais registradas em tabela | A fazer |
| BK-15 | P1 | Modelar chassi e carenagem em CAD | Enricco | BK-14 | 10/09 | Modelo contém suportes, furos e folgas | A fazer |
| BK-16 | P1 | Imprimir corpos de prova | Enricco | BK-15 | 12/09 | Furos, motor e tampa testados | A fazer |
| BK-17 | P1 | Corrigir CAD após teste de encaixe | Enricco | BK-16 | 15/09 | Peças encaixam sem força ou folga excessiva | A fazer |
| BK-18 | P1 | Imprimir peças definitivas | Danilo | BK-17 | 20/09 | Base, tampa e suportes sem defeitos críticos | A fazer |
| BK-19 | P1 | Montar sensor com divisor de tensão | Gabriel | BK-05, BK-18 | 22/09 | ECHO chega ao ESP32 com aproximadamente 3,3 V | A fazer |
| BK-20 | P1 | Validar parada diante de obstáculo | Guilherme | BK-19 | 24/09 | Avanço bloqueado abaixo de 20 cm | A fazer |
| BK-21 | P1 | Organizar cabos, bateria e chave geral | Danilo | BK-18, BK-19 | 25/09 | Cabos protegidos e bateria firmemente presa | A fazer |
| BK-22 | P1 | Executar plano completo de testes | Laura | BK-20, BK-21 | 27/09 | Resultados registrados com evidências | A fazer |
| BK-23 | P1 | Corrigir falhas encontradas | Responsável do item | BK-22 | 29/09 | Nenhuma falha crítica aberta | A fazer |
| BK-24 | P1 | Publicar versão final | Todos | BK-23 | 30/09 | Código, CAD/STL, fotos, vídeo e relatório no GitHub | A fazer |
| BK-25 | P2 | Implementar LEDs ou buzzer | Gabriel | BK-24 | Após 30/09 | Não pode atrasar os itens P0 ou P1 | A fazer |

## Distribuição de responsabilidades

| Integrante | Responsabilidade principal |
|---|---|
| Enricco Rossi | Medições, CAD, chassi e carenagem 3D |
| Gabriel Marquez | Alimentação, ponte H L298N, sensor e conferência elétrica |
| Guilherme Silva | Firmware do ESP32, controle Wi-Fi e integração de software |
| Danilo Urze | Montagem, impressão, organização física e testes dos motores |
| Laura Claro | Requisitos, Kanban, registros, evidências e revisão da documentação |

Todos os integrantes participam da validação do MVP e da revisão final.

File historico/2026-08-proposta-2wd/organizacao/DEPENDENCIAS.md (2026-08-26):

# Dependências do projeto

As tarefas foram organizadas para que o grupo saiba o que pode ser executado em paralelo e o que bloqueia a próxima etapa.

## Fluxo principal

```mermaid
flowchart TD
    A[Requisitos e componentes] --> B[Montagem elétrica]
    A --> C[Medições físicas]
    B --> D[Teste individual dos motores]
    D --> E[Controle Wi-Fi]
    C --> F[Modelo CAD]
    F --> G[Corpos de prova]
    G --> H[Impressão definitiva]
    E --> I[MVP funcional]
    H --> J[Montagem final]
    I --> J
    J --> K[Sensor e anticolisão]
    K --> L[Testes e documentação final]
```

## Tabela de dependências

| Etapa | Depende de | Motivo | Libera |
|---|---|---|---|
| Conferência dos componentes | Requisitos definidos | Confirma modelos, tensões e dimensões | Montagem elétrica e medições |
| Montagem da alimentação | Conferência dos componentes | Evita polaridade ou tensão incorreta | Ligação da L298N e do ESP32 |
| Ligação ESP32-L298N | Alimentação segura | O teste não deve ocorrer sem GND comum e fonte correta | Teste individual dos motores |
| Teste dos motores | Ligação ESP32-L298N | Confirma canais, sentido e capacidade da fonte | Controle Wi-Fi integrado |
| Controle Wi-Fi | Firmware gravado e motores testados | A interface precisa comandar um circuito funcional | MVP |
| Base provisória | Dimensões gerais dos componentes | Deve sustentar os itens sem bloquear as rodas | Montagem do MVP |
| MVP integrado | Controle Wi-Fi, motores e base provisória | Reúne todas as funções essenciais | Validação do MVP |
| Modelo CAD | Medições com paquímetro | O CAD depende das dimensões reais | Corpos de prova |
| Corpos de prova | Modelo CAD inicial | Validam furos, folgas, encaixes e eixos | Correção do CAD |
| Impressão definitiva | Correção após os encaixes | Evita desperdício de material | Montagem mecânica final |
| Sensor ultrassônico | Alimentação segura e suporte impresso | Exige 5 V, divisor no ECHO e posição frontal livre | Anticolisão |
| Testes finais | Montagem mecânica, elétrica e firmware | Só podem validar o conjunto completo | Produto concluído |

## Atividades que podem ocorrer em paralelo

- firmware Wi-Fi e conferência dos componentes;
- documentação de gestão e montagem elétrica;
- compra/separação de parafusos e medição das peças;
- desenvolvimento do suporte do sensor e testes do HC-SR04 em bancada;
- produção das evidências e execução dos testes.

## Caminho crítico

O caminho com maior risco de atrasar a conclusão é:

**medir componentes -> modelar em CAD -> imprimir corpos de prova -> corrigir CAD -> imprimir peças definitivas -> montar -> testar**.

Qualquer atraso de medição ou impressão afeta diretamente a montagem final. Por isso, o firmware e o circuito serão validados primeiro em bancada e em uma base provisória.

## Principais bloqueios e respostas

| Bloqueio | Impacto | Ação preventiva |
|---|---|---|
| Componente ainda não medido | CAD incorreto | Medir todas as peças antes da modelagem final |
| Impressora indisponível | Atraso do chassi | Reservar horário e manter base provisória para o MVP |
| Motor girando ao contrário | Movimento incorreto | Inverter os fios ou a constante correspondente no firmware |
| ESP32 reiniciando ao acelerar | MVP instável | Separar alimentação dos motores, manter GND comum e verificar a fonte |
| Esteira escapando | Carrinho não realiza curvas | Ajustar alinhamento, guias laterais e tensão |
| ECHO ligado diretamente | Risco ao GPIO do ESP32 | Usar divisor de 1 kΩ e 2 kΩ antes do GPIO 19 |

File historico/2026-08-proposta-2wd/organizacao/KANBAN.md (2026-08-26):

# Kanban do projeto

**Data da atualização:** 25/08/2026  
**Limite sugerido de trabalho em andamento:** até 3 tarefas simultâneas.

## Quadro atual

| Backlog | A fazer | Em andamento | Em teste | Concluído |
|---|---|---|---|---|
| BK-14 Medir peças | BK-05 Alimentação e GND | BK-04 Conferir componentes | BK-03 Firmware gravado no ESP32 | BK-01 Requisitos e croqui |
| BK-15 Modelar CAD | BK-06 Ligar ESP32-L298N |  |  | BK-02 Firmware e página Wi-Fi |
| BK-16 Imprimir corpos de prova | BK-07 Testar motores |  |  | BK-03 Upload no ESP32 validado |
| BK-17 Corrigir CAD | BK-08 Corrigir sentidos |  |  | Diagrama elétrico produzido |
| BK-18 Imprimir peças finais | BK-09 Testar página no celular |  |  |  |
| BK-19 Montar HC-SR04 | BK-10 Base provisória |  |  |  |
| BK-20 Testar anticolisão | BK-11 Integrar base e eletrônica |  |  |  |
| BK-21 Organizar cabos e bateria | BK-12 Validar MVP |  |  |  |
| BK-22 Executar testes finais | BK-13 Publicar Tarefa 17 |  |  |  |
| BK-23 Corrigir falhas |  |  |  |  |
| BK-24 Publicar versão final |  |  |  |  |
| BK-25 LEDs ou buzzer |  |  |  |  |

## Próximas movimentações

1. Ao finalizar **BK-04**, mover **BK-05** para “Em andamento”.
2. Após conferir alimentação e GND, executar **BK-06** e **BK-07**.
3. Se os dois motores responderem corretamente, mover **BK-09** para “Em teste”.
4. Construir a base provisória em paralelo com os testes elétricos.
5. Quando BK-08, BK-09 e BK-11 estiverem concluídos, iniciar **BK-12 - Validar MVP**.

## Regras do Kanban

- toda tarefa deve possuir responsável e critério de aceitação;
- tarefas bloqueadas devem registrar o motivo e a ação necessária;
- uma tarefa somente vai para “Concluído” depois da validação;
- o quadro deve ser atualizado sempre que houver mudança de estado;
- itens opcionais não podem ocupar o lugar de uma tarefa P0;
- cada atualização relevante deve ser registrada por commit no GitHub.

## Modelo para atualização semanal

| Data | Tarefa | Estado anterior | Novo estado | Responsável | Evidência/observação |
|---|---|---|---|---|---|
| DD/MM/AAAA | BK-XX | A fazer | Em andamento | Nome | Link do commit, foto ou resultado |

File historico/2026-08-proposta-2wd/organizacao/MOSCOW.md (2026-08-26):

# Priorização MoSCoW

O método MoSCoW foi utilizado para controlar o escopo e evitar que funcionalidades adicionais prejudiquem a entrega do carrinho funcional.

## Must Have - obrigatório

| ID | Funcionalidade | Justificativa |
|---|---|---|
| M-01 | ESP32 como placa controladora | É o controlador definido pelo grupo e fornece Wi-Fi integrado |
| M-02 | Dois motores DC controlados pela L298N | Permitem tração diferencial e realização das curvas |
| M-03 | Avançar, recuar, esquerda, direita e parar | São os movimentos essenciais do carrinho |
| M-04 | Controle Wi-Fi pelo celular | É a interface principal definida para o projeto |
| M-05 | Chassi capaz de sustentar os componentes | Garante a montagem física e o deslocamento do conjunto |
| M-06 | Alimentação segura e GND comum | Evita danos aos módulos e funcionamento instável |
| M-07 | Parada automática por perda de comando | Reduz o risco de movimento descontrolado |
| M-08 | Sensor HC-SR04 com divisor no ECHO | Detecta obstáculos sem aplicar 5 V diretamente ao ESP32 |
| M-09 | Bloqueio do avanço diante de obstáculo | Evita colisões frontais |
| M-10 | Código e documentação publicados no GitHub | Compõem a entrega e permitem reprodução do projeto |

## Should Have - importante

| ID | Funcionalidade | Justificativa |
|---|---|---|
| S-01 | Chassi e carenagem definitivos impressos em 3D | Protegem e organizam os componentes |
| S-02 | Tampa removível | Facilita manutenção e troca da bateria |
| S-03 | Controle de velocidade por PWM | Melhora a condução e o alinhamento do carrinho |
| S-04 | Esteiras com ajuste de tensão | Evita que as esteiras escapem durante as curvas |
| S-05 | Chave geral liga/desliga | Permite desligamento rápido e seguro |
| S-06 | Indicador de distância na página | Ajuda a verificar o funcionamento do HC-SR04 |
| S-07 | Registro de fotos, vídeo e resultados | Demonstra a validação do produto |

## Could Have - interessante

| ID | Funcionalidade | Justificativa |
|---|---|---|
| C-01 | LEDs de estado | Indicam ligado, conectado e obstáculo detectado |
| C-02 | Buzzer | Pode emitir alerta de obstáculo ou bateria fraca |
| C-03 | Indicador de nível da bateria | Facilita o planejamento de recarga |
| C-04 | Modo semiautônomo simples | Permite parar e desviar de obstáculos |
| C-05 | Personalização estética da carenagem | Aproxima o resultado da referência visual |

## Won't Have - não terá nesta versão

| ID | Funcionalidade | Motivo |
|---|---|---|
| W-01 | Câmera e transmissão de vídeo | Aumentam consumo, custo e complexidade |
| W-02 | GPS | Não é necessário para testes em ambiente interno |
| W-03 | RFID | Não contribui para o objetivo principal do MVP |
| W-04 | Display OLED | A interface já será exibida no celular |
| W-05 | Aplicativo Android ou iOS nativo | A página hospedada pelo ESP32 atende ao controle básico |
| W-06 | Controle remoto pela internet | O projeto utilizará rede local do ESP32 |
| W-07 | Versão com quatro motores | O projeto adotará dois motores e tração diferencial |
| W-08 | Navegação autônoma avançada | Será avaliada somente após a conclusão da versão atual |

## Regra de mudança de escopo

Uma funcionalidade nova só poderá entrar no projeto se todos os itens **Must Have** estiverem concluídos, se não alterar a data final e se houver aprovação do grupo. Caso contrário, será registrada para uma versão futura.

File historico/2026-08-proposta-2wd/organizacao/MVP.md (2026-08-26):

# MVP - Minimum Viable Product

## 1. Objetivo

Entregar a menor versão funcional do carrinho-robô capaz de se movimentar com segurança e ser controlada por um celular. O MVP comprovará a integração entre **ESP32**, **ponte H L298N**, **dois motores DC**, alimentação e interface web via Wi-Fi.

O chassi do MVP pode utilizar uma montagem provisória ou a primeira versão impressa em 3D. O acabamento definitivo da carenagem não é necessário para validar o funcionamento essencial.

## 2. Marcos e datas

| Marco | Data planejada | Condição para aprovação |
|---|---:|---|
| Protótipo eletrônico | 27/08/2026 | ESP32 aciona separadamente os dois motores pela L298N |
| MVP minimamente funcional | 29/08/2026 | Carrinho executa avançar, recuar, esquerda, direita e parar pelo celular |
| Documentação da Tarefa 17 | 01/09/2026 | MVP, MoSCoW, Backlog, Dependências e Kanban publicados |
| Produto final concluído | 30/09/2026 | Estrutura 3D definitiva, sensor ultrassônico, organização elétrica e testes aprovados |

## 3. Escopo do MVP

O MVP deverá possuir:

- ESP32 com firmware carregado;
- ponte H L298N ligada aos dois motores DC;
- alimentação compatível com os motores e GND comum;
- estrutura capaz de sustentar os componentes;
- rede Wi-Fi local criada pelo ESP32;
- página web acessível pelo celular em `http://192.168.4.1`;
- comandos de avançar, recuar, virar à esquerda, virar à direita e parar;
- parada automática quando o comando deixar de ser recebido;
- teste inicial realizado com as rodas ou esteiras suspensas.

## 4. Critérios de aceitação do MVP

| Código | Critério | Como validar | Resultado esperado |
|---|---|---|---|
| MVP-01 | Inicialização | Ligar o ESP32 e observar a rede Wi-Fi | Rede `Carrinho-ESP32` disponível em até 30 segundos |
| MVP-02 | Acesso pelo celular | Conectar à rede e abrir o endereço local | Página de controle carregada corretamente |
| MVP-03 | Motor esquerdo | Acionar somente o canal A da L298N | Apenas o motor esquerdo gira |
| MVP-04 | Motor direito | Acionar somente o canal B da L298N | Apenas o motor direito gira |
| MVP-05 | Movimentos | Acionar todos os botões da interface | Cinco comandos executados corretamente |
| MVP-06 | Parada | Soltar o botão ou tocar em parar | Motores param imediatamente |
| MVP-07 | Fail-safe | Interromper o envio de comandos | Carrinho para automaticamente em até 1 segundo |
| MVP-08 | Alimentação segura | Verificar o circuito antes do teste | Motores não são alimentados pelo ESP32 e todos os GNDs estão interligados |

## 5. Produto final

Após a validação do MVP, a versão final deverá acrescentar:

- chassi e carenagem definitivos impressos em 3D;
- tampa removível e fixações com parafusos;
- duas esteiras alinhadas e tensionadas;
- sensor HC-SR04 instalado na parte frontal;
- bloqueio do avanço quando houver obstáculo a menos de 20 cm;
- bateria fixada, chave geral e cabos protegidos;
- controle de velocidade por PWM;
- evidências de montagem e testes no GitHub.

## 6. Definição de pronto

O produto será considerado concluído quando:

1. todos os requisitos classificados como **Must Have** estiverem aprovados;
2. o carrinho operar por pelo menos 10 minutos sem reiniciar ou apresentar aquecimento anormal;
3. nenhum cabo tocar nas esteiras ou em partes móveis;
4. o sensor impedir uma colisão frontal durante o teste;
5. fotos, vídeo, código-fonte e resultados dos testes estiverem registrados no repositório;
6. o grupo realizar uma revisão final e não houver bloqueios críticos no Kanban.

## 7. Fora do MVP

Não fazem parte da primeira versão: câmera, GPS, RFID, display OLED, aplicativo nativo, navegação autônoma avançada e controle pela internet. Esses itens aumentariam o risco de *feature creep* antes da validação das funções essenciais.

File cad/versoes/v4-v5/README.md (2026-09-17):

# v4 e v5 — etapas mencionadas, arquivos não disponíveis

O relatório v6 enviado pelo usuário descreve uma etapa com tampa em encaixe rabo-de-andorinha, janela superior e extensão do rasgo da base. A v6 removeu essa tampa e estendeu novamente o rasgo.

Não foram fornecidos STLs/fontes identificados inequivocamente como v4 ou v5 nesta consolidação. Não foram reconstruídos arquivos fictícios nem atribuídos ensaios a essas revisões. A referência disponível é o relato da transição v5 → v6, registrado na pasta v6.

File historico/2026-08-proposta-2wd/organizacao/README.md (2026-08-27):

# Organização do projeto - Carrinho-robô

Documentação de organização das **Tarefas 17 e 18** da disciplina **Project-based Maker Lab**.

## Identificação

| Campo | Informação |
|---|---|
| Instituição | FIAP |
| Turma | 4ESPX |
| Professora | Gedeane Kenshima |
| Grupo | Start-up One |
| Projeto | Carrinho-robô com ESP32 |
| Repositório | [Carrinho-Robo](https://github.com/GuilhermeSSantos2004/Carrinho-Robo) |
| Prazo da Tarefa 17 | 01/09/2026 às 23h59 |
| Prazo da Tarefa 18 | 03/09/2026 às 23h59 |

## Integrantes

| Integrante | RM |
|---|---:|
| Enricco Rossi de Souza Carvalho Miranda | RM551717 |
| Gabriel Marquez Trevisan | RM99227 |
| Guilherme Silva dos Santos | RM551168 |
| Danilo Urze Aldred | RM99465 |
| Laura Claro Mathias | RM98747 |

## Entregáveis

| Documento | Conteúdo |
|---|---|
| [MVP](MVP.md) | Escopo mínimo, datas, critérios de aceitação e definição de pronto |
| [MoSCoW](MOSCOW.md) | Priorização das funcionalidades em Must, Should, Could e Won't |
| [Backlog](BACKLOG.md) | Tarefas, responsáveis, dependências, prazos e estado |
| [Dependências](DEPENDENCIAS.md) | Ordem de execução e bloqueios entre as tarefas |
| [Kanban](KANBAN.md) | Situação atual das atividades do projeto |
| [Planilha de custos](planilha-custos-carrinho-robo.xlsx) | Quantidades, preços, subtotais, cenários de alimentação, lojas e links de referência da Tarefa 18 |

## Tarefa 18 — custos

A planilha possui duas abas:

- **Resumo:** compara o custo com oito pilhas AA e com o pack Li-Ion;
- **Custos:** apresenta os itens editáveis, quantidades, preços unitários, subtotais calculados por fórmula, status, lojas e URLs.

Os preços foram consultados em **27/08/2026**, sem frete. Carenagem e materiais de montagem ainda estão marcados como `A definir` e não entram nos totais até que o grupo informe os valores.

## Resumo do planejamento

| Marco | Data planejada | Resultado esperado |
|---|---:|---|
| MVP minimamente funcional | 29/08/2026 | Carrinho realiza os cinco movimentos por controle Wi-Fi |
| Entrega da Tarefa 17 | 01/09/2026 | Documentação de gestão publicada no GitHub |
| Produto final concluído | 30/09/2026 | Chassi e carenagem impressos, ultrassônico ativo e testes concluídos |

> As datas são metas de planejamento e devem ser atualizadas no Kanban caso ocorram mudanças durante a execução.

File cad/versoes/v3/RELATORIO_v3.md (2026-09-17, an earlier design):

# Suporte reforçado para motor TT — v3 (T03)
Revisão estrutural real a partir das falhas relatadas na versão anterior.
Todas as medidas em mm. Eixos: **Z** = vertical (comprimento do motor), **Y** =
largura da carcaça amarela (22 mm confirmado), **X** = profundidade / direção
do eixo até a roda.

---

## 1. O que mudou em relação à versão anterior

| Problema relatado | Causa provável | O que foi feito nesta v3 |
|---|---|---|
| Folga lateral grande | Vão interno projetado em 38 mm para uma carcaça de 22 mm | Vão interno recalculado para **22,4 mm** (22,0 + 0,2 mm de folga por lado) |
| Peça frontal quebrou no aperto | Presilha fina (4 mm) de 62 mm de vão, trabalhando como mola/viga em balanço | Substituída por **tampa apoiada em duas orelhas maciças**, ligadas à base por **gussets** — a carga do parafuso vai direto para a estrutura, não dobra uma lâmina fina |
| Laterais frágeis | Guias de 2,3 mm | Paredes laterais estruturais de **5,5 mm**, parte da mesma peça que a base (sem emenda fina) |
| Distância entre parafusos de 50 mm | Presilha longa em ponte | Parafusos aproximados para **33,4 mm** entre si (um em cada parede lateral) |
| Postes altos com alívios | Concentração de tensão nas pontas | Sem postes isolados: reforços (gussets) triangulares maciços |

---

## 2. Dimensões usadas e origem de cada uma

### Confirmadas por você (usadas sem alteração)
- Largura da carcaça amarela (Y): **22,0 mm**
- Diâmetro do eixo: **5,35 mm**
- Furo impresso de 3,6 mm passou o parafuso maior no teste físico

### Informadas no anúncio (tratadas como referência, não como certeza absoluta)
- Comprimento do motor (Z): **70 mm**
- Redução 48:1, 3–6 V, ~200 RPM a 6 V, ~28 g

### **Assumidas por mim — AINDA NÃO CONFIRMADAS no seu exemplar** ⚠️
Pesquisei motores TT genéricos equivalentes (mesma família comercial "70×22 mm")
para ter um ponto de partida realista, mas isso **não prova** que seu motor é
idêntico. Estes são os valores que o modelo usa hoje e que você precisa
validar fisicamente antes da impressão final:

| Parâmetro | Valor assumido | Onde está no `params.json` |
|---|---|---|
| Espessura do corpo em X | 18,5 mm | `motor.thickness_x_assumed` |
| Comprimento livre do eixo (fora da carcaça) | 10,0 mm | `motor.shaft_len_assumed` |
| Altura do centro do eixo a partir do fundo da caixa amarela | 9,5 mm | `motor.shaft_height_from_gearbox_bottom_assumed` |
| Diâmetro do ressalto ao redor do eixo | 9,0 mm | `motor.shaft_boss_diam_assumed` |
| Largura entre-chaves da porca pequena | 5,6 mm | `screws.nut_across_flats_assumed` |

**Isso significa que a peça atual NÃO deve ser tratada como encaixe
perfeito garantido.** É uma estrutura corrigida nos pontos que você já
comprovou estarem errados (largura e resistência do aperto), mas as
dimensões acima ainda dependem de uma foto/medição sua.

---

## 3. Ponto crítico que precisa da sua confirmação: folga axial (direção X)

Este é o item mais sensível do projeto inteiro, e por isso não posso
declarar "encaixe garantido" nessa direção:

- Distância da face frontal do motor até o **furo/rebaixo onde a roda
  assenta**: **9,5 mm**
- Comprimento livre do eixo informado no anúncio: **10 mm** (não confirmado
  no seu exemplar)
- Ou seja, a margem de folga é de apenas **~0,5 mm**.

Se o eixo do seu motor for mais curto que 10 mm, a roda não vai assentar
corretamente contra a tampa frontal. Para reduzir esse risco eu:
- Minimizei a espessura estrutural na frente (tampa de 4,5 mm, orelha de
  5 mm de projeção — ainda com parede de 2,8 mm ao redor da porca, que é
  suficiente para PLA);
- Acrescentei um **rebaixo (alívio) de 2,5 mm** na face externa da tampa
  para o cubo da roda se aproximar mais do motor, sobrando 2,0 mm de parede
  nessa região (não estrutural, só de vedação/alinhamento).

**Ação recomendada antes de imprimir a peça definitiva:** meça com um
paquímetro o comprimento de eixo exposto (da face da carcaça amarela até a
ponta) e me informe. Se for diferente de 10 mm, eu ajusto
`front_cap.thickness_x`, `screws.boss_protrusion_x` e
`structure.base_margin_front_x` no `params.json` e regenero os STLs — é
uma mudança de parâmetro, não um redesenho.

---

## 4. Caminho dos esforços (como a carga chega à base)

1. O motor apoia suas duas faces de 22 mm contra as paredes laterais
   (folga de 0,2 mm por lado) — isso já impede a maior parte do
   deslocamento lateral e da rotação em torno de Z.
2. A tampa frontal empurra o motor contra a parede traseira ao ser
   aparafusada — o aperto axial (direção X) é o que impede o motor de
   sair pela frente durante partidas/freadas/inversões.
3. Cada parafuso passa por uma **orelha maciça** (13 × 12 × 5 mm) que é
   parte da mesma peça das paredes laterais — não é um poste isolado.
4. Cada orelha tem um **gusset triangular sólido** ligando-a diretamente
   à base — a força de aperto vai da tampa → orelha → gusset → base,
   sem passar por uma seção fina que possa fletir.
5. A porca fica cativa num rebaixo hexagonal **atrás** da orelha (lado
   da cavidade do motor mas fora da zona onde o motor realmente encosta),
   então o aperto não deforma a carcaça amarela — a reação de torque fica
   na orelha, não no plástico fino.
6. A base (7 mm) e as paredes (5,5 mm) trabalham como uma peça única
   (sem emendas coladas/rosqueadas entre si), reduzindo o risco de
   delaminação entre camadas nos pontos de carga.

**O que isso NÃO prova:** validade de malha e ausência de colisão não são
ensaio de resistência. Não fiz simulação de elementos finitos nem tenho
dados de rigidez real do PLA impresso nesta orientação — a confirmação
final tem que ser o teste físico (aperto, partidas/paradas/inversões,
inspeção de trincas).

### Retenção contra rotação/deslocamento durante inversão de sentido
O projeto atual confia em:
- Encaixe lateral justo (0,2 mm/lado) — impede rotação em torno de Z e
  deslocamento em Y;
- Aperto axial pela tampa — impede deslocamento em X.

**Não modelei** furos passantes usando os furos de fixação próprios do
motor (parafuso + porca através da carcaça), porque a posição, o
diâmetro e até a existência desses furos no seu exemplar **não foram
confirmados** (item pendente da seção 3 do seu pedido). Isso é uma
retenção estrutural adicional que os suportes comerciais costumam usar —
recomendo fotografar a carcaça (as duas faces de 22 mm e a face de trás)
para eu acrescentar esse recurso numa v4, se você quiser essa retenção
extra.

---

## 5. Ferragens — o que usar e quantidade

| Item | Uso neste suporte (1 motor) | Você tem | Observação |
|---|---|---|---|
| Parafuso pequeno (8–10 mm) | 2 (tampa → porca) | 6 | Comprimento suficiente: o aperto real precisa de ~9,5 mm de curso (tampa + parede da orelha + engate na porca). Os parafusos de 27 mm ficariam sobrando muito — prefira os curtos aqui. |
| Porca que rosqueia no parafuso pequeno | 2 | (a confirmar quantidade) | Fica cativa no rebaixo hexagonal atrás de cada orelha. **Confirme a largura entre-chaves real antes de imprimir em definitivo** — o modelo assume 5,6 mm. |
| Parafuso maior (27 mm) + porca | Não usado nesta peça de teste | 7 | Reservados para quando o suporte for integrado ao chassi do robô (fixação do conjunto à base), ou para a fixação passante pelos furos próprios do motor, se confirmarmos essa opção depois. |
| Espaçador hexagonal 29–30 mm | Não usado | 6 | Não reaproveitado como limitador — o comprimento não foi verificado para essa função, conforme você pediu. |
| Arruelas | Recomendado 1 por parafuso, sob a cabeça, do lado externo da tampa | — | Distribui a carga do aperto sobre o PLA e reduz o risco do parafuso “afundar” na tampa depois de ciclos de vibração. Avise se quiser que eu redimensione o rebaixo da cabeça do parafuso para elas. |

**Para os quatro motores** (quando integrar ao chassi): serão necessários
8 parafusos pequenos + 8 porcas pequenas no total — você tem 6 parafusos
pequenos, faltam 2. As porcas pequenas você precisa confirmar quantas
tem.

---

## 6. Verificações executadas (reais, nesta sessão)

### Malha / STL
| Verificação | Corpo principal (T03A) | Tampa (T03B) |
|---|---|---|
| Malha fechada (watertight) | ✅ Sim | ✅ Sim |
| Uma única peça conectada | ✅ Sim (1 corpo) | ✅ Sim (1 corpo) |
| Faces degeneradas/quebradas | ✅ 0 encontradas | ✅ 0 encontradas |
| Volume positivo | ✅ 41.731 mm³ | ✅ 12.609 mm³ |
| Sólido topologicamente válido (BRep, `BRepCheck_Analyzer`) | ✅ Válido | ✅ Válido |

Ferramentas usadas: CadQuery/OCP para o sólido, `trimesh` para checar a
malha exportada (watertight, contagem de corpos, faces quebradas).

### Dimensões e unidades
- Todas as operações foram feitas em milímetros (padrão CadQuery); STL e
  STEP exportados sem fator de escala.
- Conferi manualmente as caixas delimitadoras (bounding box) de cada
  peça contra os parâmetros esperados após cada alteração — os números
  batem com `params.json` (ver seção 2).

### Montagem / geometria (verificado no CAD real, não em desenho ilustrativo)
- ✅ Motor (volume simplificado 22×18,5×70 mm) cabe na cavidade com a
  folga programada de 0,2 mm por lado.
- ✅ Tampa frontal encosta nas duas orelhas sem precisar se deformar
  (junta plana simples, mais um rebaixo circular de centragem em cada
  parafuso).
- ✅ Furo passante de 3,6 mm alinhado entre orelha e tampa nas duas
  posições.
- ✅ Rebaixo hexagonal cativo não atravessa a parede da orelha (sobra
  2,8 mm de material sólido).
- ✅ Janela traseira desobstrui a ponta interna do eixo (16×16 mm,
  centrada na altura assumida do eixo).
- ⚠️ Folga axial para a roda: **apenas ~0,5 mm de margem** frente ao
  comprimento de eixo assumido — ver seção 3, pendente de confirmação
  física.
- ⚠️ Não verifiquei colisão com a roda real (68 mm) além de um raio
  genérico, porque a distância real carcaça↔face interna da roda não foi
  medida no seu conjunto (você pediu explicitamente para eu não reciclar
  o valor de 8 mm da versão anterior). O modelo deixa a região de saída
  do eixo livre e aberta; a verificação final de giro livre é física.

### O que eu NÃO fiz (para não inventar certeza)
- Não rodei simulação estrutural/FEA nem apresentei propriedades
  genéricas de PLA como prova de resistência.
- Não modelei os furos de fixação próprios do motor (posição não
  confirmada).
- Não modelei a lingueta amarela inferior com precisão — deixei um vão
  de alívio genérico (10×10 mm) na base, que precisa ser conferido/ajustado
  contra o motor real.
- Não gerei G-code — os STLs devem ser fatiados no seu perfil de
  impressora.

---

## 7. Impressão

- Material: PLA (ponto de partida). PETG é uma alternativa razoável se
  quiser mais tenacidade nas orelhas/gussets, mas troca de material não
  substitui a correção estrutural já feita.
- Perfil de fatiamento sugerido: bico 0,4 mm, camada 0,20 mm, ~6
  perímetros, 5–6 camadas de topo/fundo. Não é necessário 100% de
  preenchimento — a resistência já vem da geometria (paredes e orelhas
  maciças), não do preenchimento interno.
- **Orientação de impressão sugerida:**
  - **Corpo principal (T03A):** imprimir em pé, com a base (Z=0) no
    prato — assim a carga de aperto (direção X) fica **no plano das
    camadas**, e não perpendicular a elas nas orelhas/gussets, reduzindo
    o risco de delaminação exatamente nos pontos que quebraram antes.
  - **Tampa (T03B):** imprimir deitada, com a face traseira (a que
    encosta nas orelhas) no prato — mesma lógica: a força de aperto e o
    encaixe do rebaixo hexagonal ficam no plano das camadas.
- **Suportes de impressão:** prováveis apenas sob os gussets triangulares
  (saliência em balanço) — confira no seu fatiador com o corpo nessa
  orientação; caso o fatiador não precise, ótimo, mas não estou
  prometendo isso sem você conferir no seu software.

### Estimativa de material
- Corpo principal: 41,73 cm³ de volume sólido → **~51,7 g** se fosse
  100% maciço.
- Tampa: 12,61 cm³ → **~15,6 g** se fosse 100% maciça.
- **Esta é uma estimativa por volume geométrico (densidade PLA
  1,24 g/cm³), não uma estimativa do fatiador.** Como a peça é composta
  principalmente por paredes e reforços maciços (poucas cavidades
  internas grandes), o consumo real ao fatiar com perímetros + 100% ou
  alto preenchimento deve ficar próximo desses valores; com preenchimento
  baixo pode cair um pouco nas regiões mais espessas da base. Recomendo
  conferir o número real no seu fatiador antes de finalizar.

---

## 8. Instruções de montagem (resumo)

1. Insira o motor pela abertura superior do corpo principal (T03A),
   encostando a carcaça amarela contra a parede traseira.
2. Confirme visualmente que a ponta interna do eixo fica livre na janela
   traseira e que os fios saem pelo topo aberto.
3. Coloque as duas porcas pequenas nos rebaixos hexagonais (parte de
   trás de cada orelha).
4. Encaixe a tampa frontal (T03B) contra as orelhas — os dois rebaixos
   circulares centralizam a peça.
5. Passe os parafusos pequenos pela face externa da tampa e aperte até
   a tampa encostar nas orelhas (esse encosto é o limitador — quando
   bater, o motor já deve estar firme; se ainda balançar, é sinal de que
   a espessura real do motor em X é diferente do valor assumido de
   18,5 mm, e o parâmetro `motor.thickness_x_assumed` precisa ser
   corrigido para eu regenerar a peça).
6. Verifique giro livre do eixo antes de instalar a roda.

---

## 9. Pendências que só você pode resolver

1. **Comprimento livre do eixo** (crítico — ver seção 3).
2. **Espessura real do motor em X** (18,5 mm é uma estimativa de
   referência de motores TT semelhantes, não do seu exemplar).
3. **Largura entre-chaves real da porca/espaçador hexagonal** (assumi
   5,6 mm; você pediu explicitamente para não usar 9 mm).
4. Foto da carcaça amarela (as duas faces estreitas e o fundo) para eu
   posicionar corretamente a lingueta inferior e avaliar os furos de
   fixação próprios do motor, caso você queira a retenção passante
   parafuso+porca pela carcaça numa v4.
5. Distância real carcaça↔face interna da roda com a roda encaixada
   (com régua), se quiser que eu valide a folga da roda com precisão em
   vez de um raio genérico de verificação.

Assim que tiver essas medidas, eu atualizo `params.json` e regenero os
arquivos — é uma revisão de parâmetro, não preciso remodelar do zero.

---

## 10. Arquivos entregues

- `T03A_suporte_motor_reforcado_v3.stl` — corpo principal (impressão)
- `T03A_suporte_motor_reforcado_v3.step` — corpo principal (editável)
- `T03B_frente_apoiada_v3.stl` — tampa frontal (impressão)
- `T03B_frente_apoiada_v3.step` — tampa frontal (editável)
- `build.py` — fonte paramétrica CadQuery (controla a geometria de
  verdade)
- `params.json` — todos os parâmetros dimensionais, com marcação clara
  do que é confirmado vs. assumido
- `preview_01_frontal.png`, `preview_02_traseira.png`,
  `preview_03_explodida.png`, `preview_04_detalhe_aperto.png` — gerados
  a partir do CAD real (motor e roda são volumes simplificados,
  claramente identificados como tal)
- Este relatório (`RELATORIO_v3.md`)

Não há um `T03C_limitador_v3` nesta versão: o próprio encosto da tampa
contra as orelhas funciona como limitador, então uma terceira peça não
se mostrou necessária com as informações disponíveis. Se a medição do
comprimento do eixo ou da espessura do motor mostrar que isso não é
suficiente, um limitador/calço separado pode ser adicionado na v4.

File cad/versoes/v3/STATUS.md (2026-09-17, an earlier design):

# v3 — alternativa recebida de outra IA (histórico)

Os onze arquivos recebidos foram preservados; somente o sufixo de download `(2)` foi removido dos nomes. Incluem corpo, frente apoiada, dois STEP, dois STL, fonte, parâmetros, quatro imagens e relatório original.

A proposta reforçava paredes e usava uma frente separada com parafusos e porcas. Posteriormente a tampa foi abandonada. O relatório original e suas medidas assumidas são mantidos como registro, sem converter suas alegações em confirmação física da equipe.

Este modelo não é o conjunto atual. A furação atual é 3,46 mm; não copiar o alojamento de porca presumido nem a tampa desta versão para a v7. Não houve validação física final desta versão registrada nesta consolidação.

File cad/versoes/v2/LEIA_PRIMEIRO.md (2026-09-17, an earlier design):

# Teste do motor em pé — CUBI T03 v2

Imprima **1 suporte T03A e 1 presilha T03B**, ambos a **100%**, em milímetros.
Este conjunto é um teste de bancada do encaixe do motor. A estrutura completa
do robô v1 ainda não foi redesenhada com as novas medidas.

## O que foi corrigido

O teste anterior foi dimensionado para um corpo de 70 × 22 × 18 mm.
A especificação enviada agora informa 70 × 37 × 22,5 mm e eixo de 5,35 mm.
Nesta versão há **38 mm de largura livre**, para acomodar um corpo de até
37 mm com folga lateral, e uma presilha cuja posição ajusta a espessura.
Foram conferidos envelopes de 18 a 22,5 mm de espessura e 22 a 37 mm de largura.
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

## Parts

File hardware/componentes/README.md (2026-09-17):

# Componentes — configuração atual do protótipo

Esta página registra o hardware que está sendo realmente usado na montagem atual. A lista antiga de alternativas (8 pilhas AA / pack 2S) foi substituída pelo estado físico atual do carrinho.

## Componentes principais

| Quantidade | Componente | Estado atual |
|---:|---|---|
| 1 | ESP32 DevKit V1 / NodeMCU-ESP32 | Em uso |
| 1 | Ponte H dupla L298N | Em uso, com PWM em ENA/ENB |
| 4 | Motores TT amarelos 3–6 V, redução anunciada 48:1 | Em uso |
| 1 | Sensor ultrassônico HC-SR04 | Em uso como sensor de estacionamento de ré |
| 1 | LDR | Em uso no GPIO 34 para luminosidade/tema do painel |
| 3 | Células 18650 no suporte em série | Alimentação de potência atual |
| 3 | Resistores de 1 kΩ | Divisor do ECHO do HC-SR04 (1 kΩ / 2 kΩ) |
| — | Jumpers | Interligações |
| 1 | Chassi impresso T01 | Versão atual otimizada |
| 1 | Carcaça impressa T02 | Versão atual baixa/otimizada |
| 4 | Suportes T03A | v7 |
| 4 | Presilhas T03B | v7 |
| 4 | Travas T05 | Fixação vertical dos suportes |
| 8 | Pinos/parafusos impressos T06 | 2 por motor |

## Alimentação

O suporte em uso comporta **3 células 18650 em série**:

- 3,7 V nominais por célula;
- aproximadamente **11,1 V nominal** no conjunto;
- até aproximadamente **12,6 V** com as três células carregadas a 4,2 V;
- pack ligado à entrada de potência da L298N;
- ESP32 alimentado separadamente por USB/power bank durante os testes;
- todos os GNDs devem permanecer em comum.

### Atenção aos motores

Os motores TT são 3–6 V, portanto a tensão do pack 3S é superior à especificação dos motores. O firmware trabalha com PWM reduzido durante os testes, mas isso não transforma 12,6 V em uma alimentação 6 V equivalente. Evitar velocidade máxima e verificar aquecimento. A alimentação definitiva dos motores deve ser adequada à tensão deles.

## Pinagem consolidada

| Função | GPIO |
|---|---:|
| PWM canal A (`ENA`) | 25 |
| IN1 | 26 |
| IN2 | 27 |
| PWM canal B (`ENB`) | 33 |
| IN3 | 32 |
| IN4 | 23 |
| HC-SR04 TRIG | 18 |
| HC-SR04 ECHO | 19 (com divisor) |
| LDR analógico | 34 |

## Divisor do HC-SR04

Foram usados três resistores `MPV` (marrom-preto-vermelho), equivalentes a **1 kΩ** cada:

```text
ECHO HC-SR04
   │
  1 kΩ
   │
   ├──── GPIO 19
   │
  1 kΩ
   │
  1 kΩ
   │
  GND
```

## LDR

Ligação prevista:

```text
3V3 ── LDR ──┬── GPIO 34
              │
           resistor
              │
             GND
```

O firmware exibe o ADC bruto para facilitar a calibração real de DIA / MEIA-LUZ / NOITE.

## Mecânica atual

O projeto deixou de usar o conceito inicial de kit 2WD simples. A versão atual possui **quatro motores TT**, suportes impressos individuais e peças CAD próprias. Consulte [`../../cad`](../../cad) e o histórico de desenvolvimento para as revisões mecânicas.

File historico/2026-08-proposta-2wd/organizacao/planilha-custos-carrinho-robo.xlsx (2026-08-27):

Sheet: Resumo
TAREFA 18 — CUSTOS DO CARRINHO-ROBÔ
FIAP • Project-based Maker Lab • Turma 4ESPX
IDENTIFICAÇÃO |  |  |  | INDICADORES
Projeto | Carrinho-robô com ESP32 |  |  | Menor cenário completo | R$246.38
Instituição | FIAP |  |  | Diferença Li-Ion x AA | R$5.80
Turma | 4ESPX |  |  | Itens cotados | 14
Professora | Gedeane Kenshima |  |  | Itens a definir | 2
Prazo | 2026-09-03
Data da cotação | 2026-08-27
Cenário | Total estimado | Diferença para AA | Observação
Componentes comuns | R$180.38 | -R$71.80 | Subtotal obrigatório sem alimentação, frete, protoboard e carenagem
8 pilhas AA Duracell | R$252.18 | R$0.00 | Inclui oito pilhas e dois suportes de quatro pilhas
Li-Ion com carregador disponível | R$246.38 | -R$5.80 | Usa o pack Li-Ion e considera que o grupo já possui carregador 2S
Li-Ion comprando carregador | R$284.28 | R$32.10 | Inclui o pack Li-Ion e a compra de carregador 2S
Observação: frete, carenagem e materiais ainda sem preço não entram nos totais. A planilha deve ser atualizada após cada compra.
As URLs completas e os valores unitários estão na aba Custos. Os totais são calculados automaticamente por fórmulas.

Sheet: Custos
PLANILHA DE CUSTOS — CARRINHO-ROBÔ
Preços consultados em 27/08/2026 • Valores sem frete • Edite quantidade e preço unitário para atualizar os totais
ITENS, QUANTIDADES, LOJAS E REFERÊNCIAS
ID | Categoria | Componente | Quantidade | Unidade | Preço unitário | Subtotal | Cenário | Obrigatório | Status | Loja | Link da loja | Observação
C-01 | Controle | ESP32 DevKit V1 com cabo USB | 1 | un. | R$64.99 | R$64.99 | Comum | Sim | Cotado | Casa da Robótica | https://www.casadarobotica.com/placas-embarcadas/esp/placas/placa-esp32-com-wi-fi-bluetooth-esp32s-ide-dual-core-dev-kit-v1-cabo-micro-usb | Controlador principal; dispensa HC-05/HM-10
C-02 | Acionamento | Ponte H L298N | 1 | un. | R$14.90 | R$14.90 | Comum | Sim | Cotado | Eletrogate | https://www.eletrogate.com/ponte-h-dupla-l298n | Controle independente dos dois motores
C-03 | Mecânica | Kit chassi 2WD com motores, rodas e rodízio | 1 | kit | R$54.99 | R$54.99 | Comum | Sim | Cotado | Casa da Robótica | https://www.casadarobotica.com/robotica/chassi-s/carros/kit-chassi-2-rodas | Inclui dois motores TT e rodas
C-04 | Sensor | Sensor ultrassônico HC-SR04 | 1 | un. | R$9.90 | R$9.90 | Comum | Sim | Cotado | Eletrogate | https://www.eletrogate.com/modulo-sensor-de-distancia-ultrassonico-hc-sr04 | Detecção frontal de obstáculos
C-05 | Alimentação | Conversor step-down LM2596 | 1 | un. | R$8.90 | R$8.90 | Comum | Sim | Cotado | Eletrogate | https://www.eletrogate.com/modulo-regulador-de-tensao-step-down-lm2596 | Regular a saída para 5,0 V antes de ligar o ESP32
C-06 | Conexões | Kit jumper macho-macho | 1 | kit | R$8.90 | R$8.90 | Comum | Sim | Cotado | Eletrogate | https://www.eletrogate.com/jumpers-macho-macho-40-unidades-de-10-cm | 40 unidades
C-07 | Conexões | Kit jumper macho-fêmea | 1 | kit | R$8.90 | R$8.90 | Comum | Sim | Cotado | Eletrogate | https://www.eletrogate.com/jumpers-macho-femea-40-unidades-de-20-cm | 40 unidades
C-08 | Conexões | Kit jumper fêmea-fêmea | 1 | kit | R$7.90 | R$7.90 | Comum | Sim | Cotado | Eletrogate | https://www.eletrogate.com/jumpers-femea-femea-40-unidades-de-10-cm | 40 unidades
C-09 | Proteção | Resistores de 1 kΩ e 2 kΩ | 2 | un. | R$0.50 | R$1.00 | Comum | Sim | Cotado | Eletrogate | https://www.eletrogate.com/resistores | Divisor de tensão do ECHO do HC-SR04
C-10 | Prototipagem | Mini protoboard 170 pontos | 1 | un. | R$2.90 | R$2.90 | Opcional | Não | Cotado | Eletrogate | https://www.eletrogate.com/mini-protoboard-170-pontos | Opcional; facilita conexões durante os testes
A-01 | Alimentação | Suporte para 4 pilhas AA | 2 | un. | R$4.90 | R$9.80 | Opção A | Sim | Cotado | Eletrogate | https://www.eletrogate.com/suporte-para-4-pilhas-aa-branco- | Usar dois bancos independentes de 4 pilhas
A-02 | Alimentação | Pilha AA Duracell | 8 | un. | R$7.75 | R$62.00 | Opção A | Sim | Cotado | Amazon | https://www.amazon.com.br/Duralock-Pilha-Alcalina-Unidades-Duracell/dp/B07FKWTQPH | Não ligar as oito pilhas em série
B-01 | Alimentação | Pack Li-Ion 7,4 V 2500 mAh com BMS | 1 | un. | R$66.00 | R$66.00 | Opção B | Sim | Cotado | RoboCore | https://www.robocore.net/baterias-fontes/pack-bateria-li-ion-7_4v-2500mah-com-bms | Alternativa às oito pilhas e aos suportes
B-02 | Alimentação | Carregador Li-Ion 2S | 1 | un. | R$37.90 | R$37.90 | Opção B + carregador | Condicional | Cotado | RoboCore | https://www.robocore.net/bateria/mini-carregador-bateria-litio-2s | Necessário se o grupo não possuir carregador compatível
D-01 | Mecânica | Carenagem | 1 | un. | R$0.00 | R$0.00 | A definir | Sim | A definir | A definir |  | Material e preço serão definidos pelo grupo
D-02 | Montagem | Chave, fios, parafusos e fixadores | 1 | kit | R$0.00 | R$0.00 | A definir | Sim | A definir | A definir |  | Verificar materiais já disponíveis no laboratório

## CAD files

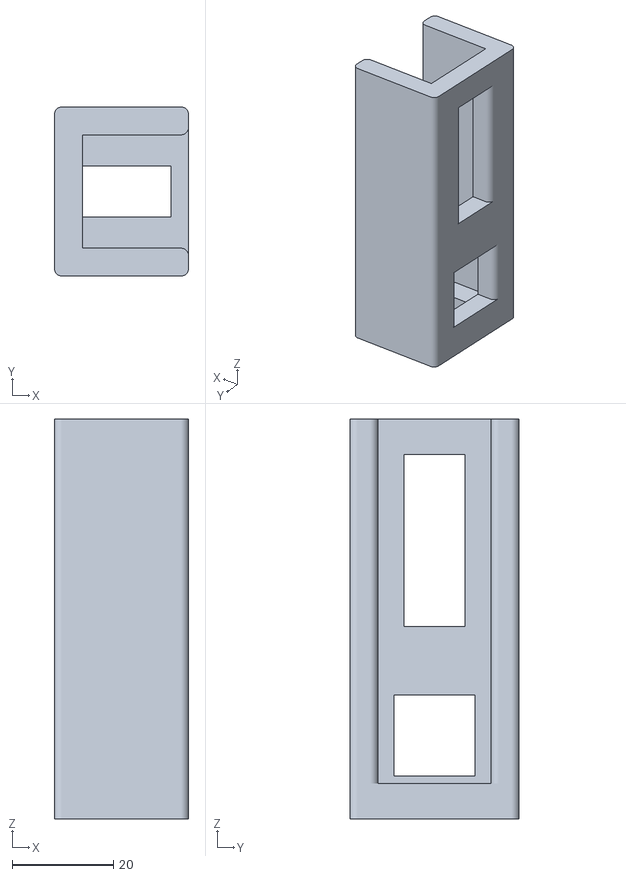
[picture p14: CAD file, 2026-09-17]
cad/versoes/v6/T03_suporte_motor_aberto_v6.stl
26.5 x 33.4 x 79.0

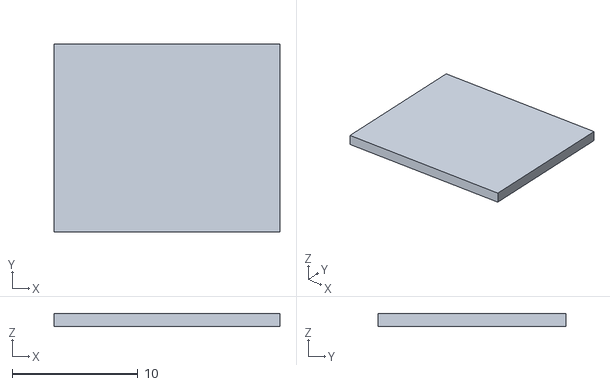
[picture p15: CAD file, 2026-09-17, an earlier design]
cad/versoes/v1/STL/13_calco_motor_1mm.stl
18.0 x 15.0 x 1.00

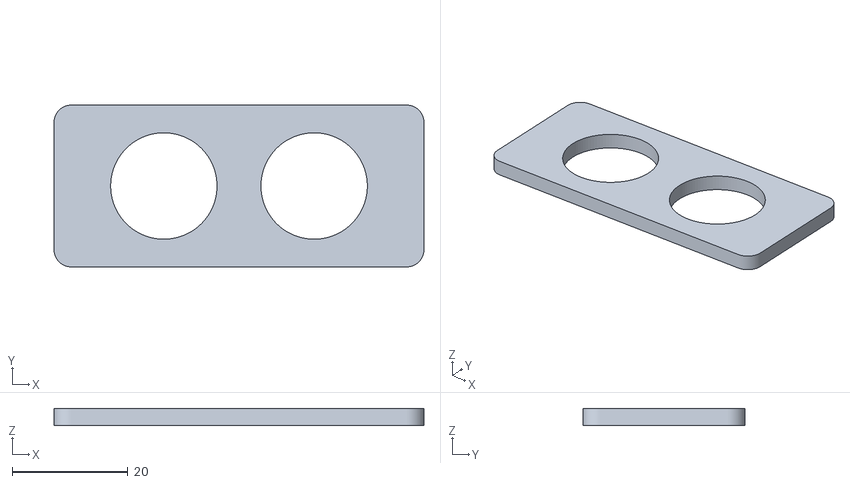
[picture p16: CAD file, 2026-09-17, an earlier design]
cad/versoes/v1/TESTES/T04_teste_olhos_hcsr04.stl
64.0 x 28.0 x 3.00

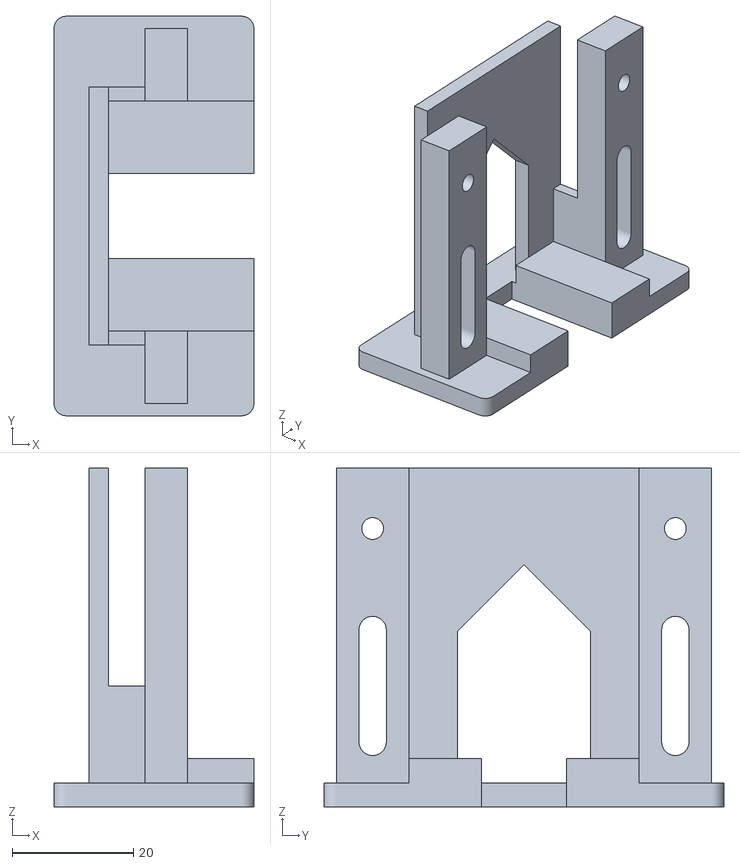
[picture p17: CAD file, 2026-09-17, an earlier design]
cad/versoes/v2/STL/T03A_suporte_motor_em_pe_v2.stl
33.0 x 66.0 x 56.0

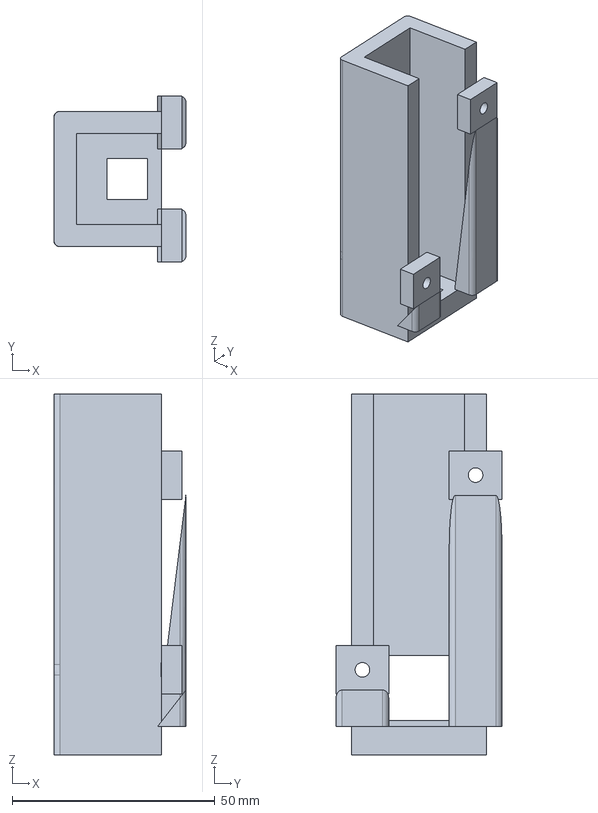
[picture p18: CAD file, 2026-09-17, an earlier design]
cad/versoes/v3/T03A_suporte_motor_reforcado_v3.step
32.5 x 40.9 x 89.0 mm

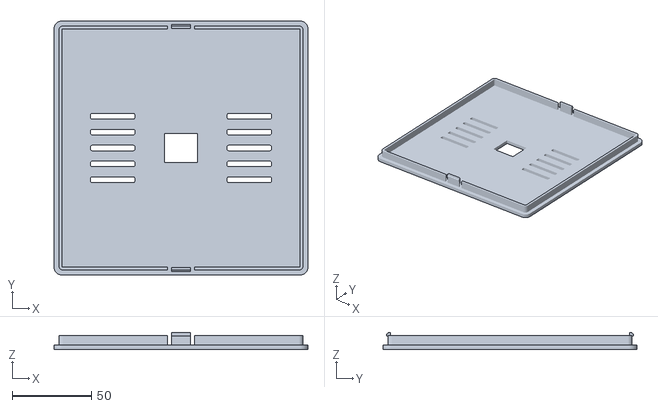
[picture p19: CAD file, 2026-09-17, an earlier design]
cad/versoes/v1/STL/04_tampa_com_travas.stl
160.0 x 160.0 x 11.0

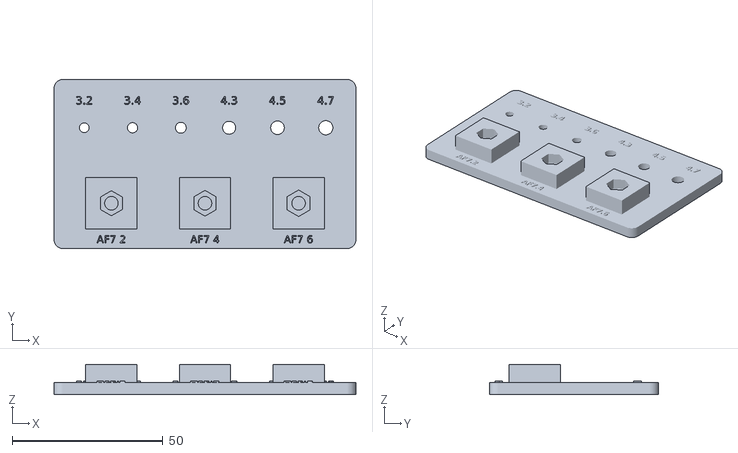
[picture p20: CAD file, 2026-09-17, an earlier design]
cad/versoes/v1/TESTES/T01_teste_parafusos_porcas.stl
100.0 x 56.0 x 10.0

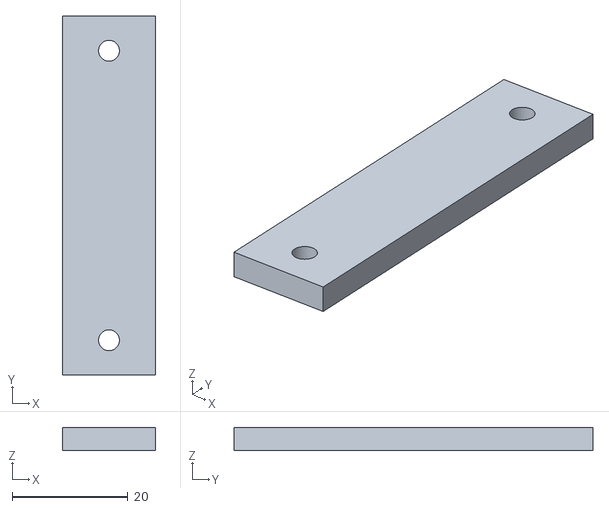
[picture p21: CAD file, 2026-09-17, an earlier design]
cad/versoes/v2/STL/T03B_presilha_regulavel_v2.stl
16.0 x 62.0 x 4.00

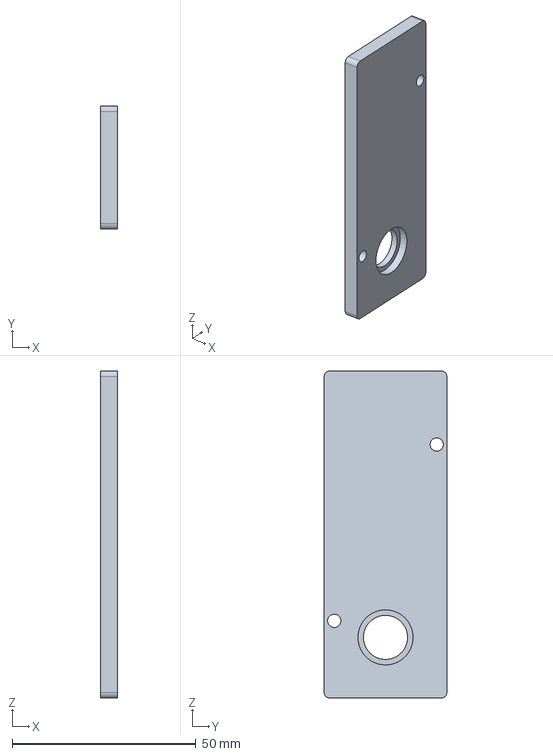
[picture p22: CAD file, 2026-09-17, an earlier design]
cad/versoes/v3/T03B_frente_apoiada_v3.step
4.50 x 33.4 x 89.0 mm

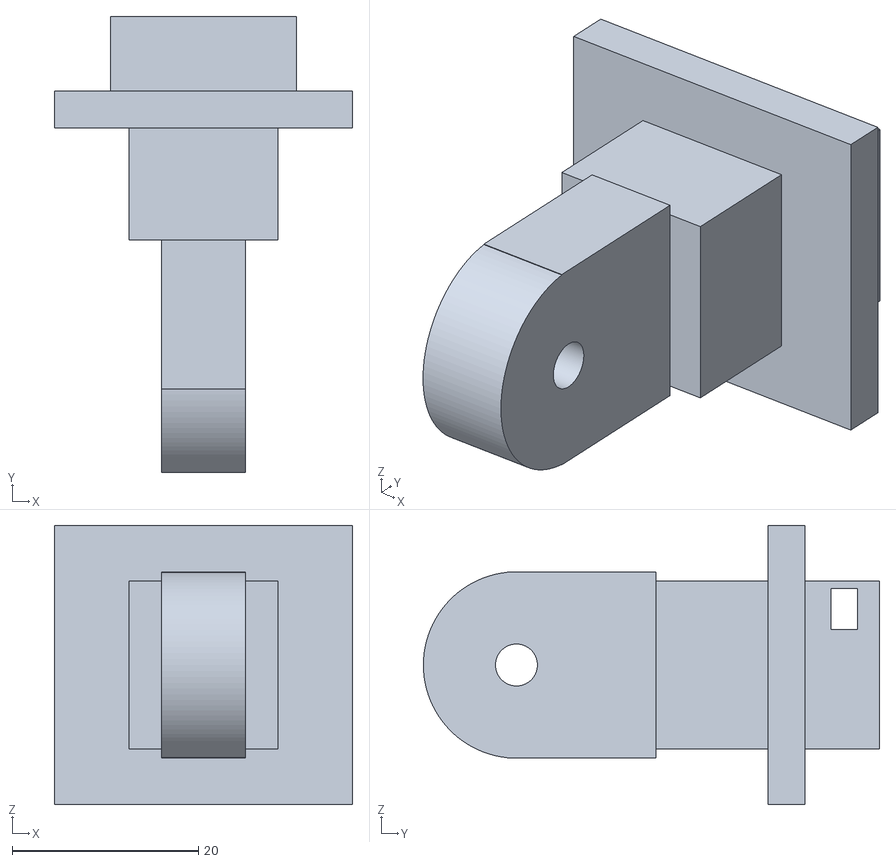
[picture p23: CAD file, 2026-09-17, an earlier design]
cad/versoes/v1/STL/06_pescoco.stl
32.0 x 49.0 x 30.0

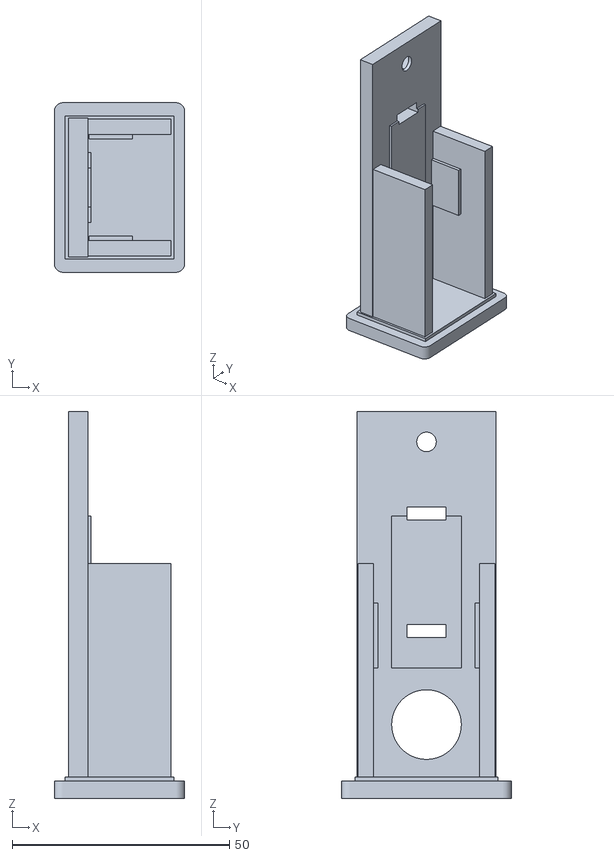
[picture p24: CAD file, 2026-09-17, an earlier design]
cad/versoes/v1/TESTES/T03_teste_berco_motor_em_pe.stl
30.0 x 39.0 x 89.0

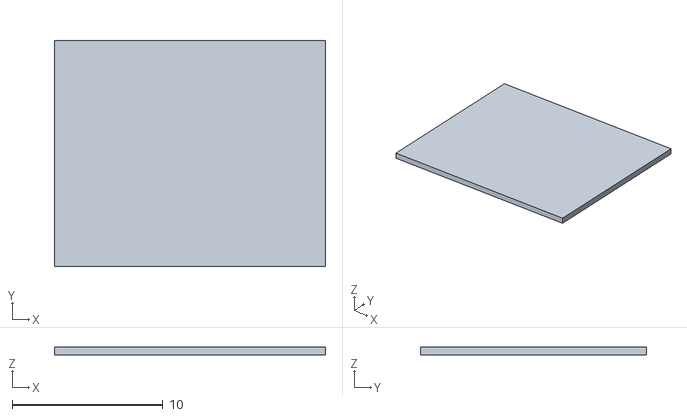
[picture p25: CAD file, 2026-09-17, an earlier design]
cad/versoes/v1/STL/12_calco_motor_0p5mm.stl
18.0 x 15.0 x 0.5

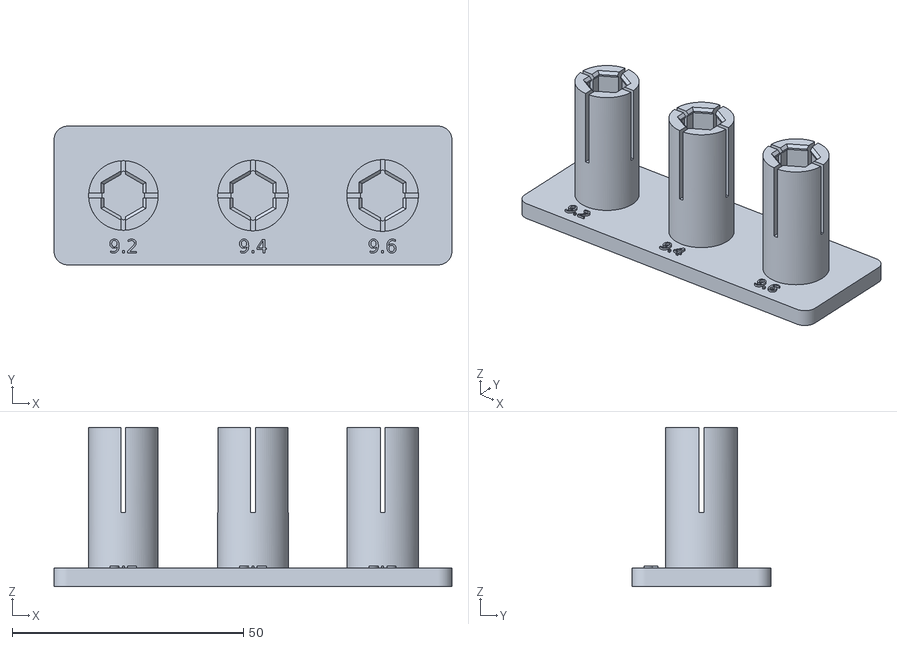
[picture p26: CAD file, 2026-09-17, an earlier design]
cad/versoes/v1/TESTES/T02_teste_hex_com_trava.stl
86.0 x 30.0 x 34.4

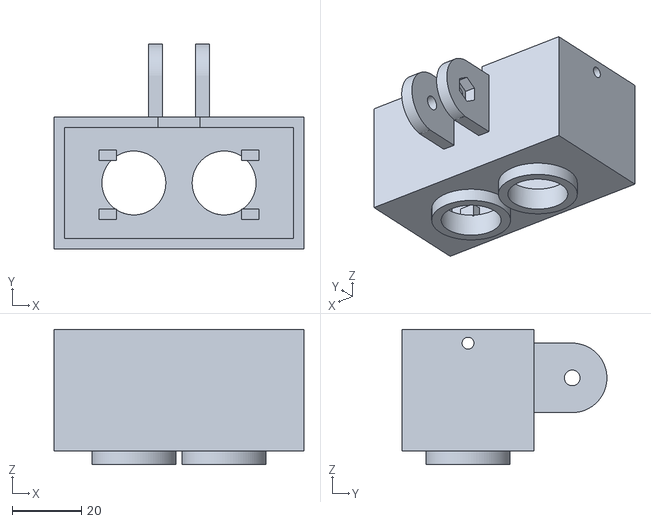
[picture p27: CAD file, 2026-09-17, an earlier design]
cad/versoes/v1/STL/08_cabeca_ultrassom.stl
72.0 x 59.0 x 39.0

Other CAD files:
cad/versoes/v1/FONTE/CUBI_04_montagem.step
cad/versoes/v2/FONTE/T03_motor_v2_montagem.step
cad/versoes/v1/STL/02_bandeja_placas.stl
cad/versoes/v1/STL/11_espacador_articulacao.stl
cad/versoes/v1/STL/01_base_bercos_verticais.stl
cad/versoes/v1/STL/03_carcaca_cubo.stl
cad/versoes/v1/STL/05_presilha_motor.stl
cad/versoes/v1/STL/07_chave_pescoco.stl
cad/versoes/v1/STL/09_tampa_cabeca.stl
cad/versoes/v1/STL/10_pino_tampa_cabeca.stl
cad/versoes/v3/T03A_suporte_motor_reforcado_v3.stl
cad/versoes/v3/T03B_frente_apoiada_v3.stl

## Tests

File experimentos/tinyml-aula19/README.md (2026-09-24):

# Aula 19 — Práticas iniciais com TinyML

**CUBI-04 · Start-up One · Experimento em fase de teste**

Esta pasta atende à preparação da atividade da profª Dra. Gedeane G. S. Kenshima, disciplina Project-based Maker Lab. A referência é o PDF **Aula 19 - Práticas iniciais com TinyML.pdf**, especialmente as páginas 8, 10–14. O firmware principal do carrinho continua em [`../../src/`](../../src/); estes sketches são independentes e não implementam controle remoto.

> **Situação:** códigos e roteiro preparados. Coleta física, mínimos/máximos observados, avaliação de ruído e CSV real ainda pendentes. Não há modelo de ML treinado: a aula pede engenharia do dado e rótulos definidos por limiares.

## O que a atividade pede

| Requisito da aula | Material | Situação |
|---|---|---|
| Escolher um sensor | HC-SR04 já documentado no carrinho | Definido; conferir módulo físico |
| Tipo da variável, valores típicos, mínimo e máximo | [RELATORIO.md](RELATORIO.md) | Especificação preenchida; observações pendentes |
| Código antes do pré-processamento | [leitura_bruta.ino](firmware/leitura_bruta/leitura_bruta.ino) | Implementado |
| Código com pelo menos 2 pré-processamentos e limiares | [leitura_processada.ino](firmware/leitura_processada/leitura_processada.ino) e [processamento.h](firmware/leitura_processada/processamento.h) | Implementado: 3 operações |
| Tipo de problema, classes e critério de rótulo | Classificação binária perto/longe | Definido |
| CSV `feature,label` com dados do sensor | `dados/dataset.csv`, gerado após coleta | **Pendente de medição real** |
| Caracterizar estabilidade e ruído | Coleta bruta com alvo imóvel e análise | **Pendente de medição real** |

## 1. Preparar o circuito

Use o **ESP32 DevKit V1 / ESP32 clássico** documentado no repositório. Se a sua placa for ESP32-S3 ou outro modelo, confirme a identificação e a pinagem antes de gravar: este exemplo não foi configurado para ela.

**Desconecte a bateria dos motores e alimente o ESP32 por USB.** Os sketches também colocam os pinos da L298N em LOW, mas a desconexão física evita acionamento durante reinício/upload. O upload substitui o programa que está na memória do ESP32; os arquivos do firmware original permanecem no GitHub.

| HC-SR04 | Ligação |
|---|---|
| VCC | 5 V da placa alimentada por USB, conforme pinagem da placa |
| GND | GND do ESP32 |
| TRIG | GPIO 18 |
| ECHO | GPIO 19 **através do divisor resistivo** |

Divisor já documentado no carrinho: ECHO → resistor de 1 kΩ → ponto conectado ao GPIO 19; desse ponto até GND, dois resistores de 1 kΩ em série. Nunca aplique o ECHO de 5 V diretamente ao GPIO. Veja a [arquitetura existente](../../hardware/arquitetura/README.md#hc-sr04--esp32).

## 2. Ler o sensor sem filtragem

1. Baixe/atualize o repositório e abra `firmware/leitura_bruta/leitura_bruta.ino` na Arduino IDE. Mantenha o nome da pasta igual ao sketch.
2. Instale o pacote **esp32 by Espressif Systems** no gerenciador de placas, se necessário. Selecione **ESP32 Dev Module** para a placa clássica documentada, e a porta COM correspondente.
3. Compile e faça upload. Se ficar preso em `Connecting...`, mantenha BOOT pressionado no início da conexão e solte quando começar a gravação.
4. Abra o Serial Monitor em **115200 baud**, preferencialmente com timestamps desativados. Pressione EN/reset com o monitor aberto para ver o cabeçalho.
5. Observe por alguns minutos. Use uma superfície plana de frente para o sensor, evitando mão inclinada e materiais absorventes.
6. Faça uma coleta com o alvo **parado a cerca de 30 cm durante 60 segundos**. Salve as linhas em `dados/serial_bruto_parado.txt`.
7. Faça outra coleta por cerca de 2 minutos, movendo o alvo entre aproximadamente 5 e 100 cm. Salve em `dados/serial_bruto_variado.txt`. Esses tempos são uma proposta de protocolo do grupo; o PDF não fixa um número de amostras.

Saída: `tempo_ms,duracao_us,distancia_cm,status`. A distância é calculada por `duracao_us × 0.0343 / 2`. O pulso original também é preservado. Não há média, normalização nem corte de distância neste sketch. `SEM_ECO` fica com distância vazia; `FORA_FAIXA` preserva o valor medido. Apenas valores `OK` entram nas estatísticas válidas.

## 3. Ler com pré-processamento

Abra `firmware/leitura_processada/leitura_processada.ino`, mantendo `processamento.h` na mesma pasta, e grave na placa. Abra o Serial Monitor em 115200 baud e reinicie a placa.

Pipeline implementado:

1. Medir aproximadamente a cada **100 ms**; timeout de eco em 30 ms.
2. Rejeitar ausência de eco e distância fora de **2–400 cm**. Uma falha reinicia a janela; não é transformada em zero nem em uma classe.
3. **Média móvel das últimas 5 leituras válidas consecutivas.** Só emitir dados quando a janela estiver completa. As cinco leituras cobrem aproximadamente 400 ms entre primeira e última.
4. **Limitação da média à faixa de trabalho de 0–100 cm.** Como só entram distâncias válidas positivas, basta limitar o teto. Distâncias maiores que 100 cm saturam em 100 cm; não significam medição exata de 100 cm.
5. **Normalização:** `feature = media_limitada_cm / 100`. Arredondar para seis casas antes de definir o rótulo.
6. Classificar a feature final, conforme a tabela.

| Label | Classe | Critério exato do CSV | Equivalência em cm |
|---|---|---|---|
| 0 | Perto | `feature < 0.200000` | média menor que aproximadamente 20 cm |
| 1 | Longe | `feature >= 0.200000` | média a partir de aproximadamente 20 cm |

O arredondamento de seis casas faz parte do critério na fronteira. O limiar de 20 cm é uma escolha **didática deste experimento**, independente do bloqueio de ré do firmware principal. São regras de rotulagem, não inferência de um modelo treinado.

Mantenha o objeto em diversas posições de cada classe: por exemplo, 5, 10 e 15 cm para perto; 25, 40, 60 e 90 cm para longe. Colete cerca de 60 segundos por classe, variando a posição a cada 10 segundos. Ao mudar a posição, aguarde cerca de 1 segundo antes de copiar um novo trecho, para a média se estabilizar. Procure números semelhantes de amostras por classe. Teste separadamente a região de 20 cm para observar oscilações de rótulo.

Copie as linhas para `dados/serial_processado.txt`. O cabeçalho será `feature,label`; as mensagens que começam com `#` são diagnósticos e não pertencem ao CSV final. Preserve o TXT original, incluindo falhas, como evidência.

## 4. Gerar CSV e conferir os dados

Abra o terminal dentro de `experimentos/tinyml-aula19`. Requer **Python 3.9 ou superior**, sem instalar bibliotecas. No Windows use `py`; no Linux/macOS substitua por `python3`.

```powershell
py ferramentas/dados.py importar dados/serial_bruto_parado.txt --tipo bruto --saida dados/bruto_parado.csv
py ferramentas/dados.py importar dados/serial_bruto_variado.txt --tipo bruto --saida dados/bruto_variado.csv
py ferramentas/dados.py importar dados/serial_processado.txt --tipo processado --saida dados/dataset.csv
py ferramentas/dados.py analisar dados/dataset.csv --tipo processado
```

A ferramenta remove cabeçalhos repetidos, comentários e timestamps usuais do Arduino IDE (`HH:MM:SS.mmm ->`). Verifica números finitos, faixa da feature, classes e coerência dos rótulos. Recusa linhas numéricas corrompidas e não sobrescreve arquivos existentes; para repetir, use um novo nome de saída. Não insere nem inventa amostras.

Na coleta bruta, imprime mínimo, máximo, média, amplitude, desvio padrão e contagens de falhas. Use o arquivo com alvo parado para falar de **ruído e estabilidade**. A variação da coleta com movimento não é uma medida de ruído do sensor.

Você também pode montar o CSV manualmente conforme a aula: cabeçalho `feature,label`, uma medição por linha, ponto decimal e vírgula separando as duas colunas. Não inclua timestamps nem diagnósticos. Não substitua valores ausentes por zero. Evite o Excel alterar o separador para ponto e vírgula.

## 5. O que enviar para concluir

- Foto legível da placa (nome do módulo) e das conexões do HC-SR04/divisor.
- `serial_bruto_parado.txt` e `serial_bruto_variado.txt`, ou os CSVs correspondentes.
- `serial_processado.txt` e, se conseguir gerar, `dataset.csv`.
- Distância aproximada do alvo parado, duração de cada coleta e observações sobre variações/falhas.
- Foto/print do Serial Monitor em cada sketch. Se ocorrer erro, envie o texto completo da compilação/upload.

Com esses arquivos, é possível preencher os resultados reais no [relatório](RELATORIO.md), verificar as duas classes e preparar a entrega. Não entregar apenas a estrutura da pasta como se a prática física já estivesse concluída.

## Limitações e próximos passos

A média reduz oscilações rápidas, mas gera atraso; perto do limiar as classes podem alternar. Temperatura, ângulo, tamanho e material do alvo afetam a medição. Não implementamos histerese para manter o critério de rótulo explícito da aula. Se houver futuro treinamento, separar treino/teste por sessão de coleta, pois janelas consecutivas compartilham dados. Um modelo treinado com rótulos desta regra aprenderá a reproduzir a regra; isso não demonstra capacidade de evitar colisões.

Para voltar ao carrinho, abra uma cópia de `src/codigo.ino` em uma pasta chamada `codigo`, compile e faça upload do firmware original; teste com rodas suspensas antes de recolocar em uso.

## Validação de software

Veja [VALIDACAO.md](VALIDACAO.md). Os testes utilizam entradas sintéticas isoladas e **não constituem CSV de entrega**.

## Referências

- Aula 19 — Práticas iniciais com TinyML, PDF fornecido pelo usuário, pp. 8 e 10–14.
- [Datasheet HC-SR04 (ElecFreaks, hospedado pela SparkFun)](https://cdn.sparkfun.com/datasheets/Sensors/Proximity/HCSR04.pdf): faixa nominal, alimentação e temporização.
- [Referência Arduino: pulseIn](https://docs.arduino.cc/language-reference/en/functions/advanced-io/pulseIn/).
- [Pinagem e circuito atuais do CUBI-04](../../hardware/arquitetura/README.md).

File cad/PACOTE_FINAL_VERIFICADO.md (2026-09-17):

# Pacote mecânico final — inventário verificado

Em 17/09/2026 foi conferido o pacote `CUBI-04_repositorio.zip` usado na consolidação da entrega. O pacote contém os modelos mecânicos finais em STL e STEP, além dos renders e dos arquivos-fonte de geração.

## STL finais

| Arquivo | SHA-256 |
|---|---|
| `T01_base_chassi_v1.stl` | `eb64ccd5b728aa3ce2f8b160ebef9cd1e81fa0a3d14aa14748b384381642305c` |
| `T02_carcaca_v1.stl` | `9b4c74ce3a754fc66779b3ae2e0d0ffea1d1760d4863c7cae51cd6d99ce83dc4` |
| `T03A_suporte_motor_aberto_v7.stl` | `1b4f494099ab446d756b681ace3d8390ba343970f59e3a85a4496e2a93cc28c6` |
| `T03B_presilha_v7.stl` | `e65e6fa5079b8d87c6a786d873d4d220bf53251bb336876b7a3b894bafdc7488` |
| `T04_tampa_v1.stl` | `894785a0115170fdad9715474bdeabdb31b1233d6b3c461079fbf7900beb78af` |
| `T05_trava_suporte_v1.stl` | `0202201d90d9ec08bd58d6263ee7dc37cd8a5a2172c9f7130945414904fc596a` |
| `T06_parafuso_impresso_v1.stl` | `8e09148ae6e9c72c7688725af7122d77d876e5d0a4f64d4d473b7b8cb2c83511` |

## STEP finais

| Arquivo | SHA-256 |
|---|---|
| `T01_base_chassi_v1.step` | `907477189530a6f01eaff79e6aa77952d9f9b10e0a2464bdf6efef55730cbb65` |
| `T02_carcaca_v1.step` | `8737f48c88260a81ec5d25846c98632ce5a4bc6420e5fa0dac8719e87c722759` |
| `T03A_suporte_motor_aberto_v7.step` | `ec309c6073ea3a58ec07f1d7b32a8e39c2e7bd9a57f6e382311b846af1a79539` |
| `T03B_presilha_v7.step` | `f15c2e12e6e2008218491065167eecdb93f8b645d5295cb5df8e29f3a431a640` |
| `T04_tampa_v1.step` | `50d0887749ea48dd972534e23c443c1fb0de447dbde7a9dbfcb8606c0868868c` |
| `T05_trava_suporte_v1.step` | `385f0c6d7cf7f90e43712e57b2066a0a4c8016779b65527ac65001fefe49b5d1` |
| `T06_parafuso_impresso_v1.step` | `9f41aad4f2deeca0bcca9a79a810803459fbbd6a9142674f999cbb4bc29a2e6e` |

## Renders presentes no pacote

O pacote contém registros visuais do desenvolvimento, incluindo `preview_carro_montado_04_completo.png`, `preview_carro_montado_03_frente.png`, `preview_chassi_otimizado.png`, `preview_carcaca_otimizada.png`, `preview_chassi_base_esp32_bateria.png`, vistas fechadas, explodidas, suporte/presilha e parafuso impresso.

## Arquivos-fonte

O pacote também contém `mecanico/src/build.py` e `mecanico/src/chassis.py`, usados como fontes do processo de geração/modelagem mecânica.

## Observação

Os hashes acima permitem comprovar exatamente quais arquivos foram usados no pacote consolidado da entrega e evitam confusão entre versões anteriores e a configuração final. O histórico das versões anteriores permanece no repositório porque faz parte do critério de evolução do projeto.

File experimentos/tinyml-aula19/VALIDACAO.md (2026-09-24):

# Validação — 24/09/2026

## Executado neste ambiente

- Leitura das instruções do PDF e conferência dos requisitos da página 14.
- Pinagem conferida com `hardware/arquitetura/README.md` e `src/codigo.ino` do repositório.
- **6 testes Python aprovados:** importação com timestamps/comentários, rejeição de valores corrompidos, rejeição de coleta vazia, preservação de falhas brutas, validação estrita do CSV final e proteção de arquivo existente na importação.
- **Teste C++ aprovado**, compilado com `g++ -std=c++11 -Wall -Wextra -Werror`: aquecimento da janela, média móvel, fronteira de 20 cm, saturação em 100 cm, reinício após falhas, limites físicos e rejeição de NaN/infinito.
- Dados sintéticos usados somente nos testes de software, não apresentados como medições reais.

Comandos para repetir a partir desta pasta:

```bash
python3 -m unittest discover -s tests -v
g++ -std=c++11 -Wall -Wextra -Werror tests/test_processamento.cpp -o /tmp/test-tinyml
/tmp/test-tinyml
```

## Limitações e pendências

- **Compilação dos sketches para ESP32 ainda não validada.** Arduino CLI foi obtido, mas a instalação do core não pôde baixar os índices: `network is unreachable`. O teste C++ usa a lógica real de `processamento.h`, mas não substitui a compilação Arduino nem valida as APIs/pinos na placa.
- Upload, comunicação serial, montagem elétrica e execução física não testados neste ambiente.
- CSV do sensor, mínimo/máximo observado, ruído e estabilidade ainda dependem da coleta física.
- A validação do CSV verifica formato e coerência dos rótulos; não prova que os dados vieram do sensor. Guardar TXT original, fotos e registro de coleta.

Na Arduino IDE, conferir o modelo da placa, selecionar o core ESP32 instalado e compilar os dois sketches. Enviar o texto completo de qualquer erro e registrar a versão do core usada.

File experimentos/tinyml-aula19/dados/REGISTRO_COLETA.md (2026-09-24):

# Registro da coleta real

Ainda não há medições nesta pasta. Preencher após executar os sketches.

| Campo | Preencher |
|---|---|
| Data/hora e responsável | |
| Modelo da placa e sensor | |
| Arduino IDE / versão do core ESP32 | |
| Arquivo e versão/commit do firmware usado | |
| Alvo: material, tamanho e orientação | |
| Alimentação e divisor ECHO conferidos | |
| Distância do alvo parado e referência (régua/trena) | |
| Duração de cada sessão | |
| Posições aproximadas no ensaio variável | |
| Condições do ambiente e falhas observadas | |
| Nomes dos TXT/CSV e capturas correspondentes | |

Arquivos previstos: `serial_bruto_parado.txt`, `serial_bruto_variado.txt`, `serial_processado.txt`, `bruto_parado.csv`, `bruto_variado.csv` e `dataset.csv`.

Não copiar as entradas dos testes automatizados para estes arquivos. Guardar o TXT original; timestamps adicionados pelo Serial Monitor não devem ir ao CSV final.

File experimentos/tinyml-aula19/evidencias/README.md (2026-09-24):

# Evidências pendentes

Após a prática, adicionar foto da placa e das ligações, captura do Serial Monitor com leitura bruta e outra com `feature,label`. Registrar distâncias/condições em `../dados/REGISTRO_COLETA.md`.

Não há evidência de teste físico deste experimento nesta versão. As fotos anteriores do carrinho não comprovam a execução destes sketches.

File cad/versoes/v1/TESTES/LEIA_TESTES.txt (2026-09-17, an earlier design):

IMPRIMA PRIMEIRO, SEM BATERIAS

1. T01 testa passagem de parafusos e alojamentos das porcas M4.
2. T02 testa um espaçador hexagonal de 29 mm x 9 mm. O soquete da base é o 9,4 mm. Se o seu hexágono tiver outra medida, ajuste antes de imprimir a base.
3. T03 + uma presilha 05 testam o motor vertical e um parafuso M4 x 27 com porca. Confira eixo, ressaltos e fixação da roda.
4. T04 testa as duas cápsulas do HC-SR04 e o espaçamento de 26 mm.

Unidades mm, escala 100%. PETG é preferível para os soquetes com trava.
Não force peças que não encaixem. Envie medidas e fotos com régua para ajustar o projeto.

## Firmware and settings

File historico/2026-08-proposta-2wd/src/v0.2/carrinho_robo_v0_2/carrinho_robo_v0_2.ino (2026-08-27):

/*
  Carrinho-robô Wi-Fi com ESP32, L298N, 2 motores e HC-SR04

  Firmware: v0.2
  Tarefa 18: acréscimo do sensor ultrassônico e bloqueio de obstáculos

  Rede criada pelo ESP32:
    Nome: Carrinho-ESP32
    Senha: carrinho123
    Painel: http://192.168.4.1

  Desenvolvido para Arduino-ESP32 3.x.
*/

#include <Arduino.h>
#include <WiFi.h>
#include <WebServer.h>

// -------------------- Wi-Fi e servidor --------------------
constexpr char FIRMWARE_VERSION[] = "0.2";
const char* WIFI_NAME = "Carrinho-ESP32";
const char* WIFI_PASSWORD = "carrinho123";  // Minimo de 8 caracteres.

IPAddress localIP(192, 168, 4, 1);
IPAddress gateway(192, 168, 4, 1);
IPAddress subnet(255, 255, 255, 0);

WebServer server(80);

// -------------------- L298N --------------------
// Remova os jumpers ENA e ENB do L298N para controlar a velocidade por PWM.
constexpr uint8_t PIN_ENA = 25;
constexpr uint8_t PIN_IN1 = 26;
constexpr uint8_t PIN_IN2 = 27;
constexpr uint8_t PIN_ENB = 33;
constexpr uint8_t PIN_IN3 = 32;
constexpr uint8_t PIN_IN4 = 14;

constexpr uint32_t PWM_FREQUENCY = 10000;
constexpr uint8_t PWM_RESOLUTION = 8;  // Valores de 0 a 255.

// Motores montados espelhados normalmente precisam de um lado invertido.
// Se um lado girar ao contrario, troque true/false somente aqui.
constexpr bool LEFT_MOTOR_INVERTED = false;
constexpr bool RIGHT_MOTOR_INVERTED = true;

// -------------------- HC-SR04 --------------------
constexpr uint8_t PIN_TRIG = 18;
constexpr uint8_t PIN_ECHO = 19;
constexpr float STOP_DISTANCE_CM = 20.0F;
constexpr uint32_t ULTRASONIC_INTERVAL_MS = 100;

// O ECHO do HC-SR04 trabalha em 5 V. Use divisor resistivo:
// ECHO -- 1 kOhm -- GPIO 19 -- 2 kOhm -- GND.

// -------------------- Seguranca --------------------
constexpr uint32_t COMMAND_TIMEOUT_MS = 800;

enum class Direction : uint8_t {
  Stop,
  Forward,
  Backward,
  Left,
  Right
};

Direction currentDirection = Direction::Stop;
uint8_t currentSpeed = 180;
float distanceCm = -1.0F;
bool obstacleBlocked = false;
uint32_t lastCommandAt = 0;
uint32_t lastUltrasonicAt = 0;

// -------------------- Pagina web --------------------
const char INDEX_HTML[] PROGMEM = R"HTML(
<!doctype html>
<html lang="pt-BR">
<head>
  <meta charset="utf-8">
  <meta name="viewport" content="width=device-width,initial-scale=1,maximum-scale=1,user-scalable=no">
  <title>Carrinho ESP32</title>
  <style>
    :root { color-scheme: dark; font-family: system-ui, -apple-system, sans-serif; }
    * { box-sizing: border-box; -webkit-tap-highlight-color: transparent; }
    body { margin: 0; min-height: 100vh; display: grid; place-items: center; background: #07111f; color: #e5eefb; }
    main { width: min(94vw, 430px); padding: 22px; border-radius: 24px; background: #101d30; box-shadow: 0 24px 70px #0008; }
    h1 { margin: 0 0 4px; font-size: 1.55rem; }
    .subtitle { margin: 0 0 18px; color: #94a9c7; }
    .status { display: grid; grid-template-columns: 1fr 1fr; gap: 10px; margin-bottom: 18px; }
    .card { min-height: 72px; padding: 12px; border-radius: 15px; background: #182a43; }
    .card small { display: block; color: #9cb0cc; }
    .card strong { display: block; margin-top: 5px; font-size: 1.1rem; }
    .blocked { color: #ff8c8c; }
    .free { color: #75e6a7; }
    .pad { display: grid; grid-template-columns: repeat(3, 1fr); gap: 12px; user-select: none; touch-action: none; }
    button { min-height: 78px; border: 0; border-radius: 18px; color: white; background: #243b5d; font-size: 2rem; font-weight: 800; box-shadow: inset 0 -4px #0004; }
    button:active, button.active { transform: translateY(2px); background: #2e65b7; box-shadow: inset 0 -2px #0005; }
    button.stop { background: #b62d45; }
    .empty { visibility: hidden; }
    .speed { margin-top: 20px; }
    .speed-row { display: flex; justify-content: space-between; margin-bottom: 8px; }
    input[type=range] { width: 100%; accent-color: #5ea1ff; }
    .hint { margin: 16px 0 0; color: #8ea4c3; font-size: .85rem; text-align: center; }
  </style>
</head>
<body>
  <main>
    <h1>Carrinho ESP32</h1>
    <p class="subtitle">Controle Wi-Fi local • Firmware v0.2</p>

    <section class="status">
      <div class="card"><small>Distancia frontal</small><strong id="distance">-- cm</strong></div>
      <div class="card"><small>Estado</small><strong id="state" class="free">Pronto</strong></div>
    </section>

    <section class="pad" aria-label="Controles de movimento">
      <span class="empty"></span>
      <button data-dir="F" aria-label="Avancar">▲</button>
      <span class="empty"></span>
      <button data-dir="L" aria-label="Virar a esquerda">◀</button>
      <button data-dir="S" class="stop" aria-label="Parar">■</button>
      <button data-dir="R" aria-label="Virar a direita">▶</button>
      <span class="empty"></span>
      <button data-dir="B" aria-label="Recuar">▼</button>
      <span class="empty"></span>
    </section>

    <section class="speed">
      <div class="speed-row"><span>Velocidade</span><strong id="speedValue">180</strong></div>
      <input id="speed" type="range" min="90" max="255" value="180" step="5">
    </section>

    <p class="hint">Segure uma seta para mover. Solte para parar.</p>
  </main>

  <script>
    const speed = document.querySelector('#speed');
    const speedValue = document.querySelector('#speedValue');
    const distance = document.querySelector('#distance');
    const state = document.querySelector('#state');
    const buttons = [...document.querySelectorAll('button[data-dir]')];
    let activeDirection = 'S';
    let keepAlive = null;

    speed.addEventListener('input', () => speedValue.textContent = speed.value);

    function updateStatus(data) {
      distance.textContent = data.distance < 0 ? '-- cm' : `${data.distance.toFixed(1)} cm`;
      state.textContent = data.blocked ? 'Obstaculo' : (data.command === 'S' ? 'Parado' : 'Movendo');
      state.className = data.blocked ? 'blocked' : 'free';
    }

    async function sendCommand(direction) {
      try {
        const response = await fetch(`/api/cmd?dir=${direction}&speed=${speed.value}`, {cache: 'no-store'});
        updateStatus(await response.json());
      } catch (_) {
        state.textContent = 'Sem conexao';
        state.className = 'blocked';
      }
    }

    function stopKeepAlive() {
      if (keepAlive) clearInterval(keepAlive);
      keepAlive = null;
      buttons.forEach(button => button.classList.remove('active'));
    }

    function startMovement(event) {
      event.preventDefault();
      const button = event.currentTarget;
      const direction = button.dataset.dir;
      stopKeepAlive();
      activeDirection = direction;
      button.classList.add('active');
      sendCommand(direction);
      if (direction !== 'S') {
        keepAlive = setInterval(() => sendCommand(direction), 250);
      }
    }

    function stopMovement(event) {
      if (event) event.preventDefault();
      if (activeDirection !== 'S') sendCommand('S');
      activeDirection = 'S';
      stopKeepAlive();
    }

    buttons.forEach(button => {
      button.addEventListener('pointerdown', startMovement);
      button.addEventListener('pointerup', stopMovement);
      button.addEventListener('pointercancel', stopMovement);
      button.addEventListener('pointerleave', stopMovement);
    });

    window.addEventListener('blur', stopMovement);
    document.addEventListener('visibilitychange', () => {
      if (document.hidden) stopMovement();
    });

    setInterval(async () => {
      try {
        const response = await fetch('/api/status', {cache: 'no-store'});
        updateStatus(await response.json());
      } catch (_) {}
    }, 500);
  </script>
</body>
</html>
)HTML";

// -------------------- Controle dos motores --------------------
void setMotor(uint8_t input1, uint8_t input2, uint8_t enablePin, int16_t power, bool inverted) {
  power = constrain(power, -255, 255);
  if (inverted) power = -power;

  if (power > 0) {
    digitalWrite(input1, HIGH);
    digitalWrite(input2, LOW);
  } else if (power < 0) {
    digitalWrite(input1, LOW);
    digitalWrite(input2, HIGH);
  } else {
    digitalWrite(input1, LOW);
    digitalWrite(input2, LOW);
  }

  ledcWrite(enablePin, abs(power));
}

void stopMotors() {
  setMotor(PIN_IN1, PIN_IN2, PIN_ENA, 0, LEFT_MOTOR_INVERTED);
  setMotor(PIN_IN3, PIN_IN4, PIN_ENB, 0, RIGHT_MOTOR_INVERTED);
  currentDirection = Direction::Stop;
}

void moveRobot(Direction direction, uint8_t speedValue) {
  if (direction == Direction::Forward && obstacleBlocked) {
    stopMotors();
    return;
  }

  currentSpeed = speedValue;
  currentDirection = direction;

  switch (direction) {
    case Direction::Forward:
      setMotor(PIN_IN1, PIN_IN2, PIN_ENA, speedValue, LEFT_MOTOR_INVERTED);
      setMotor(PIN_IN3, PIN_IN4, PIN_ENB, speedValue, RIGHT_MOTOR_INVERTED);
      break;
    case Direction::Backward:
      setMotor(PIN_IN1, PIN_IN2, PIN_ENA, -speedValue, LEFT_MOTOR_INVERTED);
      setMotor(PIN_IN3, PIN_IN4, PIN_ENB, -speedValue, RIGHT_MOTOR_INVERTED);
      break;
    case Direction::Left:
      setMotor(PIN_IN1, PIN_IN2, PIN_ENA, -speedValue, LEFT_MOTOR_INVERTED);
      setMotor(PIN_IN3, PIN_IN4, PIN_ENB, speedValue, RIGHT_MOTOR_INVERTED);
      break;
    case Direction::Right:
      setMotor(PIN_IN1, PIN_IN2, PIN_ENA, speedValue, LEFT_MOTOR_INVERTED);
      setMotor(PIN_IN3, PIN_IN4, PIN_ENB, -speedValue, RIGHT_MOTOR_INVERTED);
      break;
    case Direction::Stop:
    default:
      stopMotors();
      break;
  }
}

// -------------------- Sensor ultrassonico --------------------
float readDistanceCm() {
  digitalWrite(PIN_TRIG, LOW);
  delayMicroseconds(2);
  digitalWrite(PIN_TRIG, HIGH);
  delayMicroseconds(10);
  digitalWrite(PIN_TRIG, LOW);

  const uint32_t duration = pulseIn(PIN_ECHO, HIGH, 25000UL);
  if (duration == 0) return -1.0F;
  return (duration * 0.0343F) / 2.0F;
}

// -------------------- API web --------------------
const char* directionCode(Direction direction) {
  switch (direction) {
    case Direction::Forward: return "F";
    case Direction::Backward: return "B";
    case Direction::Left: return "L";
    case Direction::Right: return "R";
    case Direction::Stop:
    default: return "S";
  }
}

String statusJson() {
  String json = "{";
  json += "\"version\":\"";
  json += FIRMWARE_VERSION;
  json += "\",";
  json += "\"distance\":";
  json += String(distanceCm, 1);
  json += ",\"blocked\":";
  json += (obstacleBlocked ? "true" : "false");
  json += ",\"command\":\"";
  json += directionCode(currentDirection);
  json += "\",\"speed\":";
  json += String(currentSpeed);
  json += ",\"clients\":";
  json += String(WiFi.softAPgetStationNum());
  json += "}";
  return json;
}

Direction parseDirection(const String& value) {
  if (value == "F") return Direction::Forward;
  if (value == "B") return Direction::Backward;
  if (value == "L") return Direction::Left;
  if (value == "R") return Direction::Right;
  return Direction::Stop;
}

void handleCommand() {
  const Direction requestedDirection = parseDirection(server.arg("dir"));
  const int requestedSpeed = server.hasArg("speed")
    ? constrain(server.arg("speed").toInt(), 0, 255)
    : currentSpeed;

  lastCommandAt = millis();
  moveRobot(requestedDirection, static_cast<uint8_t>(requestedSpeed));

  server.sendHeader("Cache-Control", "no-store");
  server.send(200, "application/json", statusJson());
}

void handleStatus() {
  server.sendHeader("Cache-Control", "no-store");
  server.send(200, "application/json", statusJson());
}

void configureWebServer() {
  server.on("/", HTTP_GET, []() {
    server.send_P(200, "text/html; charset=utf-8", INDEX_HTML);
  });

  server.on("/api/cmd", HTTP_GET, handleCommand);
  server.on("/api/status", HTTP_GET, handleStatus);

  server.onNotFound([]() {
    server.sendHeader("Location", "/", true);
    server.send(302, "text/plain", "");
  });

  server.begin();
}

// -------------------- Arduino --------------------
void setup() {
  Serial.begin(115200);

  pinMode(PIN_IN1, OUTPUT);
  pinMode(PIN_IN2, OUTPUT);
  pinMode(PIN_IN3, OUTPUT);
  pinMode(PIN_IN4, OUTPUT);
  pinMode(PIN_TRIG, OUTPUT);
  pinMode(PIN_ECHO, INPUT);

  const bool pwmAOk = ledcAttach(PIN_ENA, PWM_FREQUENCY, PWM_RESOLUTION);
  const bool pwmBOk = ledcAttach(PIN_ENB, PWM_FREQUENCY, PWM_RESOLUTION);
  if (!pwmAOk || !pwmBOk) {
    Serial.println("ERRO: nao foi possivel configurar o PWM.");
    while (true) delay(1000);
  }

  stopMotors();
  distanceCm = readDistanceCm();
  obstacleBlocked = distanceCm > 0 && distanceCm < STOP_DISTANCE_CM;

  WiFi.mode(WIFI_AP);
  WiFi.softAPConfig(localIP, gateway, subnet);

  if (!WiFi.softAP(WIFI_NAME, WIFI_PASSWORD)) {
    Serial.println("ERRO: nao foi possivel criar a rede Wi-Fi.");
    while (true) delay(1000);
  }

  configureWebServer();

  Serial.println();
  Serial.println("Carrinho pronto.");
  Serial.print("Firmware: v");
  Serial.println(FIRMWARE_VERSION);
  Serial.print("Rede Wi-Fi: ");
  Serial.println(WIFI_NAME);
  Serial.print("Senha: ");
  Serial.println(WIFI_PASSWORD);
  Serial.print("Abra no celular: http://");
  Serial.println(WiFi.softAPIP());
}

void loop() {
  server.handleClient();

  const uint32_t now = millis();

  if (now - lastUltrasonicAt >= ULTRASONIC_INTERVAL_MS) {
    lastUltrasonicAt = now;
    distanceCm = readDistanceCm();
    obstacleBlocked = distanceCm > 0 && distanceCm < STOP_DISTANCE_CM;

    if (obstacleBlocked && currentDirection == Direction::Forward) {
      stopMotors();
    }
  }

  if (currentDirection != Direction::Stop && now - lastCommandAt > COMMAND_TIMEOUT_MS) {
    stopMotors();
  }
}

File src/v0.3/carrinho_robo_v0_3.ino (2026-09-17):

#include <WiFi.h>
#include <WebServer.h>
#include <DNSServer.h>

const char* ssid = "tony";
const char* password = "stark369";
IPAddress local_IP(192, 168, 4, 1);
IPAddress gateway(192, 168, 4, 1);
IPAddress subnet(255, 255, 255, 0);
WebServer server(80);
DNSServer dnsServer;

#define ENA 25
#define IN1 26
#define IN2 27
#define ENB 33
#define IN3 32
#define IN4 23
#define TRIG 18
#define ECHO 19
#define LDR_PIN 34

int velocidade = 80;
const float DISTANCIA_BLOQUEIO_RE = 5.0;
const unsigned long INTERVALO_LOG_LDR = 5000;
String estado = "PARADO";
float distanciaAtual = -1;
int leituraLDR = 0;
int luminosidade = 0;

float medirDistancia() {
  digitalWrite(TRIG, LOW); delayMicroseconds(2);
  digitalWrite(TRIG, HIGH); delayMicroseconds(10);
  digitalWrite(TRIG, LOW);
  long duracao = pulseIn(ECHO, HIGH, 30000);
  if (duracao == 0) return -1;
  float distancia = duracao * 0.0343 / 2.0;
  if (distancia < 2 || distancia > 400) return -1;
  return distancia;
}

void lerLuminosidade() {
  long soma = 0;
  for (int i = 0; i < 10; i++) { soma += analogRead(LDR_PIN); delayMicroseconds(200); }
  leituraLDR = soma / 10;
  luminosidade = constrain(map(leituraLDR, 0, 4095, 0, 100), 0, 100);
}

void aplicarVelocidade() { analogWrite(ENA, velocidade); analogWrite(ENB, velocidade); }
void parar() {
  digitalWrite(IN1, LOW); digitalWrite(IN2, LOW); digitalWrite(IN3, LOW); digitalWrite(IN4, LOW);
  analogWrite(ENA, 0); analogWrite(ENB, 0); estado = "PARADO"; Serial.println("[MOTOR] PARADO");
}
void frente() {
  digitalWrite(IN1, HIGH); digitalWrite(IN2, LOW); digitalWrite(IN3, HIGH); digitalWrite(IN4, LOW);
  aplicarVelocidade(); estado = "FRENTE"; Serial.println("[MOTOR] FRENTE");
}
void tras() {
  distanciaAtual = medirDistancia();
  if (distanciaAtual > 0 && distanciaAtual <= DISTANCIA_BLOQUEIO_RE) {
    parar(); estado = "RE_BLOQUEADA";
    Serial.print("[SEGURANCA] RE BLOQUEADA: "); Serial.print(distanciaAtual, 1); Serial.println(" cm"); return;
  }
  digitalWrite(IN1, LOW); digitalWrite(IN2, HIGH); digitalWrite(IN3, LOW); digitalWrite(IN4, HIGH);
  aplicarVelocidade(); estado = "TRAS"; Serial.println("[MOTOR] TRAS");
}
void esquerda() { digitalWrite(IN1, LOW); digitalWrite(IN2, HIGH); digitalWrite(IN3, HIGH); digitalWrite(IN4, LOW); aplicarVelocidade(); estado="ESQUERDA"; }
void direita() { digitalWrite(IN1, HIGH); digitalWrite(IN2, LOW); digitalWrite(IN3, LOW); digitalWrite(IN4, HIGH); aplicarVelocidade(); estado="DIREITA"; }

String pagina() {
return R"rawliteral(
<!DOCTYPE html><html lang="pt-BR"><head><meta charset="UTF-8"><meta name="viewport" content="width=device-width,initial-scale=1,maximum-scale=1,user-scalable=no"><title>Carrinho ESP32</title>
<style>*{box-sizing:border-box;touch-action:manipulation}:root{--fundo:#101010;--card:#1d1d1d;--texto:#fff;--secundario:#aaa}body{margin:0;padding:15px;background:var(--fundo);color:var(--texto);font-family:Arial,sans-serif;text-align:center;transition:.4s}body.claro{--fundo:#eee;--card:#fff;--texto:#111;--secundario:#555}body.escuro{--fundo:#101010;--card:#1d1d1d;--texto:#fff;--secundario:#aaa}.online{display:inline-block;padding:8px 18px;border-radius:20px;background:#143d20;color:#56ff7c;font-weight:bold}.luz,.distanciaBox{margin:12px auto;padding:14px;max-width:330px;background:var(--card);border-radius:16px}.distanciaNumero{font-size:55px;font-weight:bold}.temaBotao,.som{padding:10px 14px;margin:4px;border:0;border-radius:10px;background:#444;color:#fff}.temaAtivo,.som{background:#1565c0}.controle{display:grid;grid-template-columns:90px 90px 90px;grid-template-rows:90px 90px 90px;gap:10px;justify-content:center}.controle button{border:0;border-radius:20px;background:#333;color:#fff;font-size:32px}.frente{grid-column:2}.esquerda{grid-column:1;grid-row:2}.stop{grid-column:2;grid-row:2;background:#c62828!important;font-size:14px!important}.direita{grid-column:3;grid-row:2}.tras{grid-column:2;grid-row:3}.atencao{border:4px solid #ff9800}.perigo{background:#c62828!important}.critico{background:#d50000!important;animation:piscar .15s infinite}@keyframes piscar{50%{opacity:.35}}</style></head><body class="escuro">
<h1>Carrinho ESP32</h1><div class="online">● ONLINE</div><div class="luz"><div id="periodo">☀ DIA</div>Luminosidade: <strong id="luzValor">--</strong>%<br><small>ADC: <strong id="ldrRaw">--</strong></small></div>
<div><button id="autoBtn" class="temaBotao temaAtivo" onclick="tema('auto')">AUTO</button><button id="claroBtn" class="temaBotao" onclick="tema('claro')">CLARO</button><button id="escuroBtn" class="temaBotao" onclick="tema('escuro')">ESCURO</button></div>
<div class="distanciaBox" id="distanciaBox">DISTÂNCIA<div class="distanciaNumero" id="distancia">---</div>cm</div><div id="alerta"></div><p>Estado: <strong id="estado">PARADO</strong></p><button id="somBotao" class="som" onclick="toggleSom()">🔇 ATIVAR ALERTA SONORO</button>
<div class="controle"><button class="frente" onpointerdown="mover('frente')" onpointerup="parar()">▲</button><button class="esquerda" onpointerdown="mover('esquerda')" onpointerup="parar()">◀</button><button class="stop" onclick="parar()">PARAR</button><button class="direita" onpointerdown="mover('direita')" onpointerup="parar()">▶</button><button class="tras" onpointerdown="mover('tras')" onpointerup="parar()">▼</button></div><h3>Velocidade</h3><input id="slider" type="range" min="40" max="140" value="80"><p>PWM: <strong id="valor">80</strong>/255</p>
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

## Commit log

2026-08-21 docs: inclusão de videos e imagens
2026-08-26 docs: Divisão de tarefas
2026-08-27 feat: adiciona planilha de custos e firmware v0.2
    [planilha-custos-carrinho-robo.xlsx]
2026-09-16 docs(historico): preserva proposta 2WD e entregas das aulas
    [planilha-custos-carrinho-robo.xlsx]
2026-09-17 feat(cad-v1): arquiva primeiro chassi 4WD e corpos de teste
    [01_base_bercos_verticais.stl, 02_bandeja_placas.stl, 03_carcaca_cubo.stl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]
2026-09-17 feat(cad-v2): preserva suporte vertical e registra falha de fixacao
    [T03A_suporte_motor_em_pe_v2.stl, T03B_presilha_regulavel_v2.stl, T03_motor_v2_montagem.step]
2026-09-17 feat(cad-v3-v6): registra alternativas e suporte aberto de referencia
    [T03A_suporte_motor_reforcado_v3.step, T03A_suporte_motor_reforcado_v3.stl, T03B_frente_apoiada_v3.step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]
2026-09-17 feat(firmware): adiciona PWM, LDR e sensor de estacionamento de re
2026-09-17 docs(hardware): atualiza alimentação 3S, LDR, PWM e ultrassônico de ré
2026-09-17 docs(historico): aponta para histórico consolidado do checkpoint
2026-09-17 docs(cad): atualiza estado mecânico atual do T01 e T02
2026-09-17 docs(stl): registra dimensões e hashes dos modelos atuais
2026-09-17 docs(readme): consolida estado final atual do carrinho para o checkpoint
2026-09-17 docs(hardware): aponta para configuração elétrica vigente
2026-09-17 docs(checkpoint): adiciona checklist de validacao da entrega
2026-09-17 docs(historico): registra ajustes de chassi e alinhamento das rodas em 15-09
2026-09-17 docs(cad): registra pacote mecanico final e hashes dos arquivos
2026-09-17 docs(evidencias): adiciona imagens finais de chassi carenagem e suportes
2026-09-17 docs(readme): destaca carrinho final e imagens finais de fabricacao
2026-09-17 docs(evidencias): organiza imagens de montagem
2026-10-06 feat(tinyml): add synthetic ultrasonic training dataset
    [dataset.csv]
2026-10-06 feat(tinyml): add trained ultrasonic softmax model
2026-10-06 feat(tinyml): add ESP32 ultrasonic inference sketch
2026-10-06 fix(tinyml): make Arduino model include portable
    [tinyml_inferencia.ino]
2026-10-06 docs(tinyml): clarify Arduino IDE upload steps
